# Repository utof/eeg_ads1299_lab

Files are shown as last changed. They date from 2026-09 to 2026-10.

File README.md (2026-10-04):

# ADS1299 Learning Lab

**Start without buying anything.** This is a runnable Python learning environment for EEG-like signals, an illustrative electrode/input circuit, signed 24-bit conversion, data transport, signal quality, and a small machine-learning experiment.

It is **not a finished EEG recorder, a validated PCB, or permission to attach a circuit to a person**. The firmware is a board-dependent **bench-only starter** using the ADS1299's internal test/short circuits. **Rev A selects an ADS1299-4 daughterboard plus ESP32-S3-DevKitC-1-N8R8 for simulation/schematic work; none of the hardware-review or body-connection gates are approved.**

## Open these first

| File | What it does for you |
|---|---|
| [START_HERE.html](START_HERE.html) | Offline visual walkthrough, provisional digital pin map, interactive gain/offset calculator. Open with the rest of the repository available. |
| [Agent instructions](AGENTS.md) / [GitHub publication runbook](docs/REPOSITORY_PUBLICATION.md) | Fresh assistant starts here; working publication methods, review boundaries and recovery checks. |
| [Development guide](docs/DEVELOPMENT.md) | Locked installation, one quality command, test-first changes, strict typing, and enforced public interfaces. |
| [DX validation record](docs/DX_VALIDATION.md) | A dated CI run with software tests, actual ngspice execution, native helper tests, and limitations. |
| [Historical results report](docs/RESULTS.md) | Original measured outputs and evidence; retained rather than overwritten by routine CI. |
| [Learning guide](docs/LEARNING_GUIDE.md) | A beginner explanation of the electronics, simulations, signal processing, and small exercises. |
| [Hardware guide](docs/HARDWARE_GUIDE.md) | Purchasing gate, $100 budget constraint, conditional wiring, bench tests, and the body-connection boundary. |
| [Rev A hardware baseline](docs/HARDWARE_BASELINE_REV_A.md) | Selected ADS1299-4 + ESP32-S3 components, machine-readable BOM/profile, fail-closed gates, and ordered next work. |
| [Experiments guide](docs/EXPERIMENTS.md) | From synthetic alpha to a future controlled meditation experiment, without confusing artifacts with consciousness. |
| [Next-session handoff](docs/LLM_HANDOFF.md) | Give this to a future assistant together with the source and validation records. |

The earlier uploaded reports are background, not software dependencies. This package does not depend on their old ZIP links or on an AD8232/ADS1115.

## First run: Linux, macOS, or Windows

Use Python **3.11 or newer**; Python 3.13 is the development default. CI exercises clean locked installations on Linux with Python 3.11 and 3.13. macOS and Windows are not currently covered by that CI matrix. `pyproject.toml` and `uv.lock` define the current dependencies; `requirements-tested.txt` is a historical validation record.

Clone or extract the repository, then open a terminal **inside `eeg_ads1299_lab`**:

```bash
uv sync --locked --all-extras
uv run --locked python run_lab.py demo
uv run --locked python -m tools.check
```

Install **uv 0.12.18** first using the [official installation instructions](https://docs.astral.sh/uv/getting-started/installation/). The standalone installer supports an explicit version in its URL. All project commands use `uv`; do not use a separately activated environment or bare Python/pip to run or modify this project. The editable installation makes imports work outside the checkout too.

The demo makes `reports/demo/synthetic_recording.npz`, event/quality CSVs, an analysis JSON, and four PNG figures. Live commands default to ignored `reports/`; committed `results/` examples are historical evidence. Use `--out reports/my_demo` for a separate run. The seed is fixed, but numerical outputs can vary slightly across dependency versions.

The quality command checks formatting, Ruff lint, strict Pyrefly typing, cognitive complexity, Tach import boundaries, the hardware baseline, software tests, and measured branch coverage. It includes the hardware-baseline tests that formerly needed a separate discovery command. Logs and reports go under `reports/check/`, not over historical evidence.

**A successful software check is not a native-simulator, firmware-target, or hardware pass.** Run the explicit native command below for native integration. `uv run --locked python run_lab.py verify` is now a compatibility entry point to the **same** `tools.check` gate. Add `--native` for native integration; `--require-ngspice` remains an alias. There is no competing historical-report verifier.

Before making changes, read [AGENTS.md](AGENTS.md) and install both the pre-commit and commit-message hooks:

```bash
uv run --locked pre-commit install
```

## Run a circuit simulation

```bash
uv run --locked python run_lab.py circuits --out reports/circuits
```

This solves the existing illustrative passive circuit using Python's linear algebra, writes response/tolerance CSVs, and exports two `.cir` files. The numerical solver is **not ngspice**. There is no transistor-level ADS1299 model, and the next Rev A-specific input-network model is separate work.

For a real ngspice cross-check and the full native gate on Debian/Ubuntu/Linux Mint:

```bash
sudo apt update
sudo apt install --no-install-recommends ngspice g++ nodejs
uv run --locked python run_lab.py circuits --require-ngspice --out reports/circuits
uv run --locked python -m tools.check --native
```

The strict commands fail when required tools are absent. The DX CI run recorded in [DX_VALIDATION.md](docs/DX_VALIDATION.md) actually executed ngspice and compared both educational circuits with the independent numerical solution. That newer CI evidence does not change what ran in the original historical validation environment. Simulator logs remain under the output folder.

## Three useful changes

```bash
# Negative control: remove the planted condition difference.
uv run --locked python run_lab.py demo --null-effect --out reports/my_null

# Eight physical channels and 60-Hz residual line interference.
uv run --locked python run_lab.py demo --channels 8 --line-hz 60 --out reports/eight_channels

# Edit a copy of this JSON to change gain, offset, or artifact size.
uv run --locked python run_lab.py demo --config configs/demo.json --out reports/custom
```

Changing a JSON changes the **simulation**, not a physical board. The firmware does not read `configs/demo.json` or the board-review worksheet.

## Test the recording path with no electronics

```bash
uv run --locked python -m tools.check --native
```

The native gate includes the real localhost UDP loopback: nine seconds of synthetic packets with samples 1000 and 2000 deliberately omitted, CSV decoding, and a gap-safe quality report. It checks 2,248 accepted packets and two missing samples. Unexpected extra loss causes a failure rather than a reassuring-looking plot. To run only the loopback, use `uv run --locked python -m tools.run_loopback --out reports/loopback`.

For manual control, use two terminals:

```bash
# Terminal A
uv run --locked python run_lab.py receive --seconds 15 --out reports/practice.bin
```

```bash
# Terminal B, while A is listening
uv run --locked python run_lab.py replay --seconds 8 --drop-every 1000
```

Then:

```bash
uv run --locked python run_lab.py decode reports/practice.bin --out reports/practice.csv
uv run --locked python run_lab.py inspect reports/practice.csv --out reports/practice_quality
```

Keep the `.json` metadata beside the decoded CSV. New captures include a SHA-256 binding the pair; inspection rejects a mismatched generation. Legacy captures without a digest remain readable with an explicit caution. The inspector analyzes only uninterrupted four-second windows. It reports DC offset separately and never fills gaps to manufacture a continuous spectrum. The receiver defaults to localhost; actual LAN use requires `--host 0.0.0.0`, private-network firewall permission, and the computer's LAN address in the firmware. UDP is unencrypted; never expose the port to the public internet.

## What is in the source?

```text
lab/adc.py              Ideal code scaling, range/headroom checks, sinc³ model
lab/analog/            Public analog facade; internal solver, SPICE, and report modules
lab/data_types.py      Typed numerical arrays and data/report contracts
lab/validation.py      Runtime validation at external-data boundaries
lab/signals.py          Deterministic, explicitly synthetic recordings
lab/dsp.py              Quality screens, band power, session-held-out classifier
lab/protocol.py         ADS frame decoding, custom packets, CRC and counters
lab/acquisition.py      UDP/optional bench serial logging and CSV decoding
lab/inspect_capture.py  Gap-safe bench spectra and quality reports
lab/recording.py        Synthetic recording validation and atomic NPZ persistence
lab/pipeline.py         Demo outputs and figures; compatibility persistence re-exports
hardware/rev_a/         Hardware-contract facade, checker, data, and tests
firmware/              Original-ESP32 bench starter; NOT target-compiled by the DX gate
configs/               Editable demo settings and hardware-review worksheet
results/               Historical example recordings, figures, logs, and reports
reports/               Ignored outputs from current quality/simulation runs
tests/                 Regression, property, architecture, and workflow tests
tools/check.py         Shared local/CI quality command
tools/commit_messages.py Conventional Commit hook and actual-history validation
tach.toml              Enforced public interfaces and dependency direction
```

The firmware's default `BOARD_PROFILE_REVIEWED = false` intentionally prevents acquisition startup. Changing that setting acknowledges **bench digital wiring only**, not body-use approval. Do not bypass it just to see a waveform.

## Rev A input-network study

The selected Rev A input components now feed a reproducible passive-network study, rather than remaining isolated hardware JSON. Start with the numerical calculation; then run the independent simulator comparison when ngspice is installed:

```bash
uv run --locked python -m lab.rev_a --out reports/rev_a_input
uv run --locked python -m lab.rev_a --require-ngspice --out reports/rev_a_input_native
```

The study validates and loads the locked 4.99 kOhm / 4.7 nF component values and BOM tolerances, checks an ideal-source reference, compares balanced and mismatched source impedances, evaluates eight tolerance corners per case, and reports 50/60 Hz common-mode conversion plus hypothetical DC leakage sensitivity. The native command actually runs six ngspice comparisons. `uv run --locked python -m tools.check --native` includes this study and retains its evidence under `reports/check/rev_a_input/`.

All source/load/parasitic assumptions appear in the report. Clamps remain DNP. **This is not an ADS1299 silicon, distributed-cable, BIAS-loop, physical-hardware or human-use safety model.** Read the [Rev A study guide](docs/REV_A_INPUT_STUDY.md) before interpreting the numbers.

## Contributing: uv and Conventional Commits

Use `uv sync --locked --all-extras` and `uv run --locked ...` for project work. Child processes launched with `sys.executable` inherit that locked interpreter; they do not create a second environment. CI bootstraps uv itself separately, then uses the same locked commands.

Commit subjects follow [Conventional Commits 1.0.0](https://www.conventionalcommits.org/en/v1.0.0/):

```text
feat(simulation): add a Rev A input-network sweep
fix(recording): reject discontinuous sample times
refactor(acquisition): stream decoded packets
chore(dx): synchronize issue labels
```

Use lowercase `feat`, `fix`, `docs`, `style`, `refactor`, `perf`, `test`, `build`, `ci`, `chore`, or `revert`; an optional lowercase scope describes the affected component. A breaking change uses `!` after the type/scope and should explain the incompatibility in a `BREAKING CHANGE:` footer. Subjects must have a nonempty description and no trailing whitespace.

The installed `commit-msg` hook checks the subject. CI checks **actual commits introduced by the PR**, not just its title. Old history is grandfathered. Actual merge commits are exempt, but writing “Merge” on a single-parent commit is not a bypass. **Merge PRs with merge commits: no squash and no history rewriting.** Validate a range locally with:

```bash
uv run --locked python -m tools.commit_messages --base origin/main --head HEAD
uv run --locked python -m tools.check --native
```

Issues use one `type/*`, one `priority/*`, and applicable `area/*` labels. Examples: `type/bug` + `priority/high` + `area/acquisition`, or `type/refactor` + `priority/medium` + `area/dx`. [The label manifest](.github/labels.json) owns names, colors, and descriptions; trusted-main housekeeping synchronizes it without deleting unrelated labels. Merged same-repository PR branches are removed only after ancestry and exact-head checks. Active or changed branches are retained.

Read [the adversarial review](docs/ADVERSARIAL_REVIEW.md) for the architecture verdict, reproduced failures, corrections, and remaining limits.

## Troubleshooting

| Symptom | First action |
|---|---|
| `ModuleNotFoundError` | Run `uv sync --locked --all-extras` and use `uv run --locked` with the repository environment. |
| Missing ngspice or native compiler | Install the required tool; do not count numerical Python tests as native execution. |
| Quality gate failed | Read the named log and `reports/check/CHECK_REPORT.json`; do not bypass the check. |
| `All epochs rejected` | Inspect gain, differential DC offset, and quality flags. An overrange input is an expected negative test. |
| No UDP packets | First repeat localhost loopback. Then inspect the private LAN address, firewall, and UDP port. |
| No four-second spectral windows | The capture is too short or fragmented. Fix acquisition before interpreting spectra. |
| Unexpected ESP32 or board pins | Stop; the supplied firmware pin map is not generic to every ESP32/ADS1299 module. |
| Matplotlib cache permission warning | Set `MPLCONFIGDIR` to a writable directory; no special font installation is required. |

Read [SOURCES.md](docs/SOURCES.md) for primary references and [MODEL_SCOPE.md](docs/MODEL_SCOPE.md) for model boundaries.

### Bounded BIAS overload hypothesis

`uv run --locked python -m lab.rev_a_bias_overload --require-ngspice` compares
a stated one-pole rail/slew hypothesis with ngspice while preserving feedback
capacitor charge. It is not measured ADS1299 overload recovery. Read
[the scope, source limits and numerical checks](docs/REV_A_BIAS_OVERLOAD.md).

### Shared-source analog-feed hypothesis

Run `uv run --locked python -m lab.rev_a_supply` for five independently checked
startup/burst cases of the selected analog-feed path. See
[the study and its assumptions](docs/REV_A_SUPPLY_STUDY.md). A completed numerical
comparison may expose a modeled rail-margin breach; neither outcome qualifies
the board or the separate TPS7A20 model.

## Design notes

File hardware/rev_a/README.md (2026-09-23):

# Rev A component baseline

Read [the hardware decision](../../docs/HARDWARE_BASELINE_REV_A.md) first.

**Selected:** ADS1299-4PAGR, ESP32-S3-DevKitC-1-N8R8, internal ADC reference/clock,
5 V unipolar bench power, and ADC-only TPS7A2033PDBVR regulation.

**Not authorized:** fabrication, purchasing, external-input operation or body connection.
The review flags are deliberately false. These JSON files are a design contract,
not a firmware implementation or a validated KiCad schematic.

```bash
python hardware/rev_a/check_baseline.py
python -m unittest discover -s hardware/rev_a -p 'test_*.py' -v
```

Run those commands from the repository root. Python 3.10+ and no third-party
packages are required. The checker also works when invoked by absolute path.

- `board_profile.json`: selected operating point, proposed GPIO/header assignments and review gates.
- `bom.json`: exact selected MPNs, reference counts, FIT/DNP population and planning costs.
- `sources.json`: primary sources, original-report SHA-256 hashes and access limitations.

This baseline was integrated after inspecting live `main` at
`31205de841c577c373532fbc9d065fa81d0a6ac8`. The existing firmware remains
unchanged and its board/target review guard stays fail-closed. The repository's
entry-point docs link here so future work does not reopen the component decision
by accident. Run the existing project tests and ngspice baseline on this branch
before changing the analog model or porting firmware to the S3.

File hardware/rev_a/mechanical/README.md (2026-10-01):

# K2 carrier CAD — unapproved fit prototype

Open **view_k2.scad** in OpenSCAD 2021.01. Select `assembly` or `exploded` in
Customizer, or an individual part. F6 renders solids. The library is
**carrier_k2.scad**; dimensions are millimeters in the PCB coordinate system,
with PCB top z=0. No fonts or external CAD library are needed.

See [the dimension/assembly/validation record](../../../docs/REV_A_CARRIER_K2.md)
before editing or interpreting meshes. The rendered board and connectors are
reference envelopes. The assembly is not one printable part. Export only a
named part after the separate prototype/process approvals; STL export alone
is not fabrication permission.

The base has no fasteners through the PCB. Remove the raised bridges for board
installation. J1/J2 bridge fastener spacings differ (30/36 mm). Socket cartridges
have different ribs/grooves, side cable windows and permanently captured cover
concepts. Remove/release the independent cable clamp BEFORE withdrawal. Real
socket orientation, printed dimensions, capture strength and mating behavior
are not verified by a picture or finite collision samples.

The native project gate now includes actual OpenSCAD collision/mesh checks:

```sh
uv run --locked python -m tools.check --native
```

It requires the documented native tools, including OpenSCAD 2021.01; no missing-
renderer skip is a pass. All purchasing, fabrication, powered-connection and
body-use gates remain unchanged. Current PCB source identity is recorded in
the linked document and checked by the tests.

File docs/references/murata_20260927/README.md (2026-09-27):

# Dated Murata evidence, not a second BOM

Read `../../REV_A_CAPACITOR_EVIDENCE.md`. `source_record.json` retains selected
factual fields from five exact-core rows in Murata's public catalog, the official
status legend, exact technical-PDF identities and capture receipts. The English,
Japanese and Chinese status columns are retained; `channel_code=jp` is not a
worldwide inventory claim. The current BOM remains the component source of truth.

Only core-to-current-D-suffix matches are established. No generic suffix-removal
or replacement-equivalence API is introduced. Body thickness maxima in the CSV
are separate from the nominal/tolerance values visually read from the PDFs.

This historical snapshot is tested offline for consistency, not polled in CI.
Retain it when later component decisions supersede it. Manufacturer technical
exports contain typical information, not approved assembly or a guaranteed
minimum effective capacitance. No PCN/date or replacement was established.

The complete catalog, internal coefficients and JavaScript are not redistributed.
The conversation package retains the five original technical PDFs, measurement
conditions, status images and capture hashes for review. CI success is not a
source-authenticity proof or permission to use hardware.

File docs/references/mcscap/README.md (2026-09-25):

# Owned MCScap electrodes: source facts, not a fitted circuit

Recorded 2026-09-24. The user reports owning MCScap electrodes with **insulated DIN 1.5 mm connectors**. The supplied family manual calls the connector **TouchProof** and describes passive, reusable Ag/AgCl cup electrodes. The exact catalogue variant, actual lead length and shielding are not yet known. Do not treat the selected ADS1299-4/S3 baseline as hardware already purchased.

## Preserved source

- [Complete user-supplied Russian manual transcription](MCS.MCE-UM-RU-RU_2024-10-31_user_transcription.txt): all supplied sections, including warnings, technical characteristics, use, maintenance and symbols. Presentation/line wrapping is normalized; technical wording, units and unusual values are not silently corrected.
- [Source record](source_record.json): manufacturer statements and user-reported inventory are separated from unknown numerical-model inputs. `null` means unknown, not zero.

The uploaded PDF was inspected, including the technical table. Its filename was `Электроды электроэнцефалографические MCScap. Руководство по эксплуатации .pdf`, 176,340 bytes, SHA-256 `23fd5e9f5d527dcd727f6707394ed6d6c9cc860d0810d6941f80eddcd2bb049a`. **The original PDF binary is not committed here.** This directory preserves the complete supplied text and identifies the exact attachment, not a claimed byte-identical PDF copy.

The [manufacturer document catalogue](https://docs.mks.ru/ru/product/eeg-electrodes) lists document `MCS.MCE-UM-RU-RU`, revision 1.0, 2024-10-31, 172 Kb. That catalogue entry was checked; the remote PDF was not binary-hash-compared with the upload.

## What the manual actually establishes

| Printed statement | Permitted interpretation | Not established |
|---|---|---|
| Electrode impedance no more than 5 kΩ | A manufacturer specification for the electrode under its applicable test conditions | A frequency-independent 5 kΩ resistor including the user's scalp contact; the test frequency/method is absent here |
| Electrode potential difference no more than 100 mV | A stated electrode-potential-difference limit | A measured offset of this connected recording system |
| Difference drift no more than 25 µV | A stated drift limit | µV/hour: the observation interval is unspecified |
| Electrode noise voltage no more than 20 µV | A stated noise-voltage limit | RMS or peak-to-peak amplitude, bandwidth, spectral density, or a white-noise parameter |
| Cable length no more than 2.5 m | Family upper bound | The actual cable length, shielding, capacitance per metre or capacitance location |
| Dielectric strength at least 30 V | A printed electrode insulation characteristic | Mains/patient isolation of the assembled EEG system |
| Insulation resistance at least 1000 Ω | Preserved exactly as printed in the supplied PDF | Permission to silently change the unit/value or use it as a patient-fault leakage model |

The manual itself says detailed characteristics depend on the manufacturer's catalogue number. The 1.5 mm diameter is **user-reported**, not separately specified in this family manual. A touch-protected/insulated connector is not a galvanic isolation barrier for the whole device.

## Modeling policy: this user's hardware first

Keep the existing Rev A three-scenario study as the clearly labelled numerical regression fixture it is. Do not relabel its 10 kΩ/100 nF assumptions as MCScap measurements or silently replace them with 5 kΩ.

The next electrode-specific study should use this source record, the actual catalogue variant and the available lead information. Represent missing frequency-dependent electrode/contact parameters explicitly. A 5 kΩ resistive example can be an **illustrative sensitivity case**, but not a manufacturer-calibrated model. Separate selected board components, published electrode facts, justified assumptions and physical measurements in every report.

Bad or asymmetric contact is still relevant to these same electrodes: the manual requires checking impedance and correcting contact when it increases. Keep a small set of normal/unequal/disconnected scenarios for the owned hardware; do not build an electrode-plugin system, generic registry or speculative device hierarchy. Introduce a reusable abstraction only when a second real use demonstrates duplication.

Before fitting parameters, obtain the exact catalogue suffix and actual lead length/shielding, and seek the impedance/noise test conditions or suitable dummy-bench measurements. Do not infer electrode capacitance from a single impedance upper bound.

No source statement here approves the Rev A circuit, its protection, its assembly, purchasing or connection to a person. The original hardware/firmware safety gates remain unchanged and false.

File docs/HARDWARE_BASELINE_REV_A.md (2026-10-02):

# Rev A hardware baseline: ADS1299-4 + ESP32-S3 bench daughterboard

**Decision date:** 2026-09-23  
**Base repository commit:** `31205de841c577c373532fbc9d065fa81d0a6ac8`  
**Status:** component and interface baseline for simulation/schematic work; **not** fabrication, purchasing, external-input, or human-connection approval.

## Decision

Use a four-channel `ADS1299-4PAGR` daughterboard connected to an official `ESP32-S3-DevKitC-1-N8R8`. Start at 250 SPS, gain 24, SPI mode 1 at 1 MHz, with the ADS1299 internal 4.5 V reference and internal clock. Use an externally regulated 5 V unipolar analog bench rail and a `TPS7A2033PDBVR` for **ADS DVDD only**; the ESP32-S3 remains on the devkit regulator.

Each differential channel starts with two 4.99 kΩ series resistors and one 4.7 nF C0G capacitor **across INP/INN**. No input-to-ground common-mode capacitors are fitted in Rev A. BIAS starts disabled; reserve 1 MΩ || 1.5 nF feedback plus a separate 1 MΩ output resistor for later dummy-load loop testing. Optional BAV199 steering-diode footprints are DNP initially.

This deliberately resolves the component ambiguity without pretending the hardware is validated. The existing original-ESP32 firmware guard and `BOARD_PROFILE_REVIEWED=false` behavior remain unchanged.

## Current component baseline

K1 amendment (2026-09-30): the two headers are now `HTSW-110-07-T-D`,
replacing the original TSW selection after its assembly restriction was identified.
Pin mapping, lands and routing are unchanged. See `REV_A_CONNECTOR_K1.md`;
exact attachment process, hole DFM and keyed carrier remain release conditions.
The original selection and price assumptions remain in Git history.

## Exact current parts

The machine-readable source of truth is [`hardware/rev_a/bom.json`](../hardware/rev_a/bom.json). Planning costs are allowances, not live supplier quotes.

| MPN | Qty | Population | Planning line cost |
|---|---:|---|---:|
| `ADS1299-4PAGR` | 1 | FIT | $45.00 |
| `ESP32-S3-DevKitC-1-N8R8` | 1 | FIT | $15.00 |
| `TPS7A2033PDBVR` | 1 | FIT | $1.20 |
| `RC0603FR-074K99L` | 8 | FIT | $0.64 |
| `GRM1885C1H472JA01D` | 4 | FIT | $1.60 |
| `RC0603FR-071ML` | 2 | FIT | $0.20 |
| `GRM1885C1H152JA01D` | 1 | FIT | $0.35 |
| `T491D107K016AT` | 1 | FIT | $2.00 |
| `T491B226K016AT` | 1 | FIT | $1.20 |
| `GRM188R61E105KA12D` | 15 | FIT | $2.25 |
| `GRM188R71H104KA93D` | 7 | FIT | $0.70 |
| `GRM219R61A106KE44D` | 4 | FIT | $1.40 |
| `RC0603FR-0710RL` | 1 | FIT | $0.08 |
| `RC0603FR-0710KL` | 5 | FIT | $0.30 |
| `RC0603FR-0742K2L` | 7 | FIT | $0.42 |
| `HTSW-110-07-T-D` | 2 | FIT | $4.00 |
| `B6B-XH-A(LF)(SN)` | 1 | FIT | $0.50 |
| `BAV199,215` | 8 | DNP | $2.40 |

Fitted components: **$76.84**. Bare-PCB reserve: **$15.00**. Harness/mating reserve: **$3.00**. **Planning subtotal: $94.84**. Optional BAV199 population adds $2.40. Shipping, tax/VAT/import charges, assembly/stencil/setup, tools, bench instrumentation, battery/charger, enclosure, and any patient-safety hardware are excluded. The $3.00 historical harness reserve is not evidence that the newly identified IDC assemblies and coded carrier fit that allowance. Obtain one delivered basket/assembly quote before purchasing; $94.84 is not a delivered total or a demonstration that the $100 objective is met.

C4 adds a dedicated six-way J3 service connector for the auxiliary circuit:
return, actual DVDD feed OUT, separate DVDD sense, AVDD sense, return, NC.
The 20-position headers are unchanged. See `REV_A_SERVICE_C4.md` for the
1:1 harness, native placement and open solder/crimp/physical-fit requirements.
The $0.50 addition is a planning allowance only; auxiliary electronics and the
new harness/support manufacture remain outside the old budget.

## Electrical contract

### Input network

```text
source P -- 4.99k --+---- ADS INxP
                     |
                   4.7 nF C0G
                     |
source N -- 4.99k --+---- ADS INxN
```

For an ideal zero-impedance differential source, the analytical pole is:

`1 / (2*pi*(4.99k + 4.99k)*4.7nF) = 3393.06 Hz`.

That is an RFI-network reference calculation, not an EEG passband specification and not a SPICE result. Electrode/source impedance and mismatch must be swept explicitly.

### Power

```text
regulated 5.0 V bench source
  +-- 10 ohm RC feed --> quiet analog rail --> ADS AVDD / AVDD1
  +-- TPS7A2033PDBVR --> 3.3 V --> ADS DVDD only
  +-- devkit 5 V input --> onboard regulator --> ESP32-S3
```

Do not power the ESP32-S3 from the ADS DVDD regulator. Do not simultaneously power the devkit from USB and its external 5 V header. The analog feed resistor is a filter element, not a regulator; the design envelope in `board_profile.json` must remain within the ADS operating rail range.

### Reference / VCAP baseline

Use the ADS1299 internal reference and clock. The selected baseline includes 100 µF solid tantalum at VCAP1, 22 µF solid tantalum across VREFP/VREFN, local 1 µF supply/VCAP capacitors, 100 nF high-frequency bypass, and 10 µF local rail bulk capacitors. Final schematic review must verify every pin, polarity, effective capacitance under bias, and datasheet-required connection.

### Proposed S3 signal map

| Signal | ESP32-S3 GPIO | ADS1299 pin |
|---|---:|---:|
| SCLK | 12 | 40 |
| MOSI/DIN | 11 | 34 |
| MISO/DOUT | 13 | 43 |
| CS | 10 | 39 |
| DRDY | 4 | 47 |
| RESET | 5 | 36 |
| START | 6 | 38 |
| PWDN | 7 | 35 |
| CLKSEL | 8 | 52 |

This map is **proposed, not bench-verified**. GPIO8 is exposed on the official
DevKitC-1 v1.1 header and is reserved here for CLKSEL so the ADS input can stay
low during rail startup and be asserted only after supplies stabilize. J_DIG pin
19 carries CLKSEL; the former passive DVDD sense assignment is removed.

The ADS1299 power-up sequence requires its digital and analog inputs low until
the supplies stabilize. Therefore SCLK, DIN/MOSI, CS, RESET, START, PWDN and
CLKSEL all have a declared power-up level of 0 in `board_profile.json`. CS and
CLKSEL use 42.2 kΩ pulldowns after the coordinated C3 light-load migration, not pullups.
All seven receiver-side bus defaults use the same 42.2 kΩ value; the reserved
CLK/GPIO1-4 terminations stay 10 kΩ. See `REV_A_AUXILIARY_C3.md` for the
conditional loaded-high/disabled-low budget; no power-up/fault qualification follows. The intended operational CLKSEL level
remains 1 for the internal oscillator; firmware must make that transition only
after the supply-stable boundary. This contract does not claim that rail timing
has been measured. CLK itself (ADS pin 37, not pin 51) has a fitted 10 kΩ
`R_CLK_DN` to DGND: CLKSEL low selects that external-clock input during startup.
This adds one instance of the already selected resistor, a $0.06 planning allowance,
not a new part family. Clock output remains disabled.

The firmware does not load `hardware/rev_a/board_profile.json`; the explicit
`EEGLAB_REV_A_S3` header is checked against it in tests. Its reviewed path now
executes the controlled startup sequence in
[`REV_A_STARTUP_SEQUENCE.md`](REV_A_STARTUP_SEQUENCE.md). The review gate stays
false; a successful build does not authorize changing it.

**Analog startup remains a physical precondition, not a digital-GPIO result.**
The passive R/C input network does not hold a floating external input low. Before
any reviewed power-up, a separately reviewed passive startup fixture must hold
the used analog inputs low; no person or powered source may be attached. The
serial rail/fixture confirmation is only an operator acknowledgment. It neither
measures those inputs nor supplies an automatic back-powering interlock. Do not
claim that this contract alone satisfies the complete datasheet startup rule.

## Fail-closed gates

Rev A keeps all of these false:

```json
{
  "board_profile_reviewed": false,
  "firmware_port_validated": false,
  "schematic_released": false,
  "purchase_approved": false,
  "human_connection_allowed": false
}
```

No person or animal should be connected to this Rev A design. Battery operation, Wi-Fi, a USB isolator, low-leakage clamps, or a high-value BIAS resistor do not by themselves establish system safety.

## Validation

From the repository root:

```bash
uv run --locked python hardware/rev_a/check_baseline.py
uv run --locked python -m unittest discover -s hardware/rev_a -p 'test_*.py' -v
```

These checks verify the declarative BOM/profile contract, quantities, pin conflicts, cost arithmetic, frame length, provenance references, and fail-closed gates. They do **not** run SPICE, compile firmware, perform KiCad ERC/DRC, measure hardware, or certify safety.

## Next work, in order

1. **Implement the Rev A input network in ngspice.**
   a. Preserve the existing educational circuit as a regression fixture.  
   b. Add the selected 4.99 kΩ / 4.7 nF differential network and explicit source/electrode impedance.  
   c. Sweep impedance imbalance, R/C tolerance, cable capacitance, 50/60 Hz common mode, and bounded clamp leakage.  
   d. Compare the ideal case to 3393.06 Hz and commit numerical regression tests.

2. **Model BIAS and power behavior.**
   a. Add a bounded behavioral BIAS amplifier, the 1 MΩ / 1.5 nF network, dummy electrode/cable loads, and saturation.  
   b. Sweep uncertain loop parameters and check stability/recovery.  
   c. Model analog-rail startup and burst-like MCU/radio current coupling.

3. **Create the KiCad schematic and explicit ESP32-S3 firmware profile.**
   a. Use the exact BOM and four-channel pin rules.  
   b. Preserve all firmware guards and keep external-input acquisition disabled.  
   c. Compile supported targets and test ID/register readback plus 4/6/8-channel frame handling.

4. **Layout, quote, and bench bring-up.**
   a. Four-layer layout, ERC/DRC, reference/VCAP locality, controlled return paths, radio separation.  
   b. Obtain a delivered parts/fabrication/assembly quote before ordering.  
   c. Bring up rails -> ID/registers -> internal test -> input-short noise -> reviewed dummy source -> radio on/off comparison.

5. **Treat any body-connected design as a later revision.**
   a. Resolve battery/charging separation, enclosure, electrode connector/protection, BIAS fault paths, and qualified safety review.  
   b. Revalidate analog/noise behavior after those changes; bench success is not patient-safety evidence.

## Provenance

Detailed primary-source URLs, the two research-report hashes, verification notes, and the inspected upstream SHA are in [`hardware/rev_a/sources.json`](../hardware/rev_a/sources.json). Dynamic stock/pricing should be rechecked at purchasing time.

## Native schematic correction

The schematic slice removes `R_DAISY_DN`: unused DAISY_IN (pad 41) connects
directly to DGND, following TI SBAS499C section 10.1.1. The separate CLK pad 37
pulldown remains fitted. This retires one instance, not a part family, and reduces
the preceding planning total by $0.06. These are allowances, not supplier quotes.

The native schematic and its independent exported-netlist checker are described
in `REV_A_SCHEMATIC.md`. All physical review, purchasing and body-use gates stay false.

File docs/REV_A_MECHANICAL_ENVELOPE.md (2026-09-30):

# Rev A mechanical and assembly envelope M1

**Reviewed source:** `8c3440ed6714bfebaac74768a0d371401a22e89e`, tree
`81acc1aa34c29faa7a0305d2247826909a6c2f13`. Authored board SHA256
`5da65b4307f0336883da9aeae48711b28c1944ec587f5d3174f12db4e9921875`.
M1 is a selected mechanical planning envelope, not a released fixture or
manufacturing approval. No copper, holes, footprints, BOM or firmware change.

## Decision and concrete assembly blocker

**Retain the existing outline and use an external nonconductive edge carrier,
with independently supported controller and cable strain relief.** Four small
contact regions below pass a source-geometry screen. No new mounting hole is
required for this concept. Do not drill, clamp arbitrary edges, place metal
washers under the board, or use the headers as structural supports. Carrier
material, retention force, board deflection, contamination, dimensional
variation and physical fit still need a drawing and validation. The selection
is a way forward without rerouting, not proof that any generic holder fits.

**The present TSW-110-07-T-D headers must not be included in an assumed
lead-free SMT reflow process.** Samtec's TSW/HTSW catalog identifies TSW as
PBT and lists it as not lead-free solderable, with lead-wave-only processing;
it separately lists HTSW as lead-free solderable [1]. The combined SSW/TSW/SMH
specification's reflow section explicitly discusses *surface-mount* parts and
labels its temperature tables SMT [5]. Its generic reflow-pass paragraph is not
an exact-orderable exception to the through-hole TSW catalog restriction.
Tin plating or RoHS status alone is not process compatibility.

Select a staged assembly architecture: SMT components first, headers excluded
from that operation. **The subsequent header attachment process is on hold**
until the exact TSW process is accepted in writing or a high-temperature header
alternative is reviewed and migrated consistently. This is not permission to
hand-solder TSW with an unverified lead-free profile, use a leaded process, or
silently replace it with HTSW. All other stencil/land/reflow decisions stay open.

**Next bounded task:** evaluate the same-function high-temperature header route
and a polarized actual mate/strain-relief arrangement. Resolve the connector
process choice before a coordinated BOM/schematic/PCB-field/test change and
final carrier drawing. This is one connector/process decision, not a new layout
or an open-ended catalog search. Keep capacitor #48 and remaining #45 inputs open.

## What the authored board actually provides

The single Edge.Cuts rectangle runs from **(10,10) to (88,68) mm**: nominal
**78 x 58 mm**. KiCad's 78.05 x 58.05-mm graphic bounding box includes the
0.05-mm outline stroke; it is not the board's specified physical size. Finished
outline and thickness tolerances need the factory drawing. Nominal thickness
is 1.6 mm, with the previously selected but unconfirmed stackup target.

All 68 footprints are front-side; eight diode bodies are DNP. There are 205 SMD
pads and 40 plated through-hole header pads, **no NPTH mounting pads and no
separate mounting-hole footprint or internal Edge.Cuts cutout**. The 122 signal/
power vias are not mounting holes. The ground plane and buried copper remain
under some mechanically empty surface regions.

Coordinates below are top-view native board coordinates, not a mating-face
view. Both header footprint rotations are zero. Each row advances +2.54 mm
in y; odd pins are the lower-x column and even pins the higher-x column.

| Header | Function | Pad 1 (x,y) mm | Pin-grid centre mm | Pin-grid x / y range mm |
|---|---|---|---|---|
| AFE J1 | Digital/power | (80,27) | (81.27,38.43) | 80..82.54 / 27..49.86 |
| AFE J2 | Dummy analog input | (15,32) | (16.27,43.43) | 15..17.54 / 32..54.86 |

The same unkeyed 2x10 form serves electrically incompatible functions. Reversed,
one-position-offset and wrong-header mating must be prevented by the final
mechanical arrangement and verified unpowered before any later allowed test.
Labels alone are not a mechanical interlock. Do not remove an arbitrary pin:
J1's full map is assigned and J2's unused positions are still part of the
current contract. Preserve AFE/DEVKIT prefixes and the existing wiring map.
`REV_A_BENCH_HARNESS.md` now describes the actual layout rather than saying no
layout exists. No cable, keyed connector or live interface was qualified here.

## Mating allocation, not an arbitrary plug guarantee

M1 reserves **8 mm across the rows by 28 mm along them**, centred on each pin
field. These are chosen planning dimensions, not measured or manufacturer
maximum plug dimensions. They exclude fingers/tools, cable bend radius,
connector sway, tails, adapter boards and strain relief, which need their own
external volumes. No closed enclosure is selected.

| Allocation | (xmin,ymin,xmax,ymax), mm | Nearest other courtyard AABB gap | Board-edge margin |
|---|---|---:|---:|
| J1 | (77.27,24.43,85.27,52.43) | C33: 0.726 mm | 2.730 mm |
| J2 | (12.27,29.43,20.27,57.43) | D1/D3/D5/D7: 1.300 mm | 2.270 mm |

Courtyard-centreline bounding boxes conservatively screen the footprint
neighborhood, including DNP diode courtyards. They are not guaranteed assembly
or tool-clearance envelopes. The tightest neighbor is the C33 corner; changing
the plug, candidate body or placement tolerance requires rechecking it.

**Geometry reference only:** Samtec SSW-110-01-T-D is a same-pitch socket with
about 25.91-mm body length, 4.95-mm reference width and 8.51-mm height [3,4].
It has PCB tails, not a finished cable/strain-relief assembly, and is not being
added to the BOM. The drawing's +/-0.25-mm length tolerance, cut flash and sway
must be included in an actual assembly fit review; the width is marked REF.
This is a nominal fit screen, not a worst-case mate certification.

TSW style07 has a 5.84-mm nominal mating post and 2.54-mm reference body
height: nominal unmated height **8.38 mm**. The SSW insertion-depth interval is
3.68..6.35 mm [1,3]. The nominal post lies in that interval, but actual seating
and tolerances remain to be checked. Adding 2.54 and 8.51 gives **11.05 mm**
as a nominal fully seated shell-top estimate, not a guaranteed board-to-board
spacing. Carrier clamps must not obstruct withdrawal or cause board bending.

## Heights and board support

| Item | Reference maximum L x W x H, mm | Centred body-to-own-courtyard AABB margin |
|---|---|---:|
| Proposed 10-uF bulk, C30-C33 | 2.10 x 1.35 x 1.35 | 0.305 mm |
| Proposed 1-uF/100-nF, C8-C29 | 1.70 x 0.90 x 0.90 | 0.280 mm |
| Existing T491D C6 | 7.60 x 4.60 x 3.10 | 0.250 mm |
| Existing T491B C7 | 3.70 x 3.00 x 2.10 | 0.250 mm |

The candidate bulk is 0.40 mm taller than the old part but does not exceed
C6's reference height. Murata bounds come from the previously retained exact
reference records, not an 0805-name assumption; the candidates remain unadopted.
KEMET's current captured dimensions match the existing July2026 land source
[7]. Centred-body containment excludes placement error, solder, termination
fit and process tolerances, so it does not approve the land or component change.
U1's PAG drawing separately specifies 1.20-mm maximum overall height [6].

Choose **4 mm free height over the SMT field**, **15 mm open vertical space over
each header mating allocation**, at least **6 mm further unobstructed withdrawal
travel above the actual mated shell**, and **5 mm board-underside-to-base space**
as carrier design starting points. No lid/tool/fixture is qualified by those
numbers. Cable and adapter protrusions can exceed them and must be accommodated.
For scale, the nominal 2.54-mm TSW tail minus a nominal 1.6-mm board is 0.94 mm;
using the earlier overall minimum thickness1.44 gives1.10 mm before terminal
variation and solder. Neither calculation bounds the actual finished protrusion.
Inspect actual solder/tails, board warp and fixture tolerances before assembly
acceptance. Do not rely on soldermask as the fixture's insulation system.

Four selected **1.5 x 6 mm surface-contact strips** are below; dimensions are
planning allocations, not a supplied or fabricated clamp. Support and removable
retention stay within them; the base fastens outside the PCB. Add strain relief
on the carrier, not on sensitive leads or component bodies. This is not a tested
load/deflection model or permission for a suspended mating daughterboard.

| Region | (xmin,ymin,xmax,ymax), mm | Outer pad/track/via AABB gap | Courtyard gap | Mate-allocation gap |
|---|---|---:|---:|---:|
| Left upper | (10,32,11.5,38) | 1.300 | 1.730 | 0.770 |
| Left lower | (10,48,11.5,54) | 1.300 | 1.730 | 0.770 |
| Right upper | (86.5,27,88,33) | 3.110 | 2.180 | 1.230 |
| Right lower | (86.5,43,88,49) | 3.110 | 2.180 | 1.230 |

These distances are conservative AABB lower bounds on current outside copper,
not actual minimum trace-to-contact distances in three dimensions. The screen
explicitly rejects unsupported outer pours/copper graphics; there are none in
this source. It includes through vias and both outer pad/track layers. Buried
copper, mask damage, edge registration, friction, material leakage, cleanliness
and insertion forces are NOT qualified. Surface clearance is **not permission
to drill into these locations** or automatically reserve a copper keepout.

Samtec recommends independent support for board-to-board mating [5]. M1 applies
that principle through an external carrier because the present PCB has no
mount holes. Actual insertion/extraction force and permissible board strain
must be determined with the chosen mate and carrier, not guessed from pin count.

The existing 1.00-mm header drills also differ from the manufacturer's 1.02-mm
nominal callout [2]. A nominal0.635-mm square post has a0.898-mm diagonal, but
that arithmetic does not include terminal, hole/plating or positioning tolerances.
Keep hole/annulus and process review open; no automatic drill or pad resize.

## Reproduce the source screen

Run this read-only block from the repository root using the system Python
which supplies the pinned KiCad9.0.2 `pcbnew` module. It does not refill/save the
board or create a production dependency. It derives the counts, header grids,
rectangles, gaps and centred-capacitor projections, then checks the retained
record. The record's parameters are chosen allowances; the code does not
revalidate vendor drawings, mechanical force or a real fixture. AABB distance
is deliberately conservative, not a generic exact collision solver.

```python
import hashlib
import json
import math
from pathlib import Path
import pcbnew as k

record = json.loads(Path("docs/checkpoints/20260930_mechanical_envelope.json").read_text())
path = Path("hardware/rev_a/layout/rev_a.kicad_pcb")
assert hashlib.sha256(path.read_bytes()).hexdigest() == record["board_sha256"]
assert k.Version() == "9.0.2"
b = k.LoadBoard(str(path))

def point(p):
    return [p.x / 1e6, p.y / 1e6]

def box(p):
    return [p.GetX() / 1e6, p.GetY() / 1e6, p.GetRight() / 1e6, p.GetBottom() / 1e6]

def span(points):
    return [
        min(p[0] for p in points),
        min(p[1] for p in points),
        max(p[0] for p in points),
        max(p[1] for p in points),
    ]

def separation(a, z):
    return math.hypot(max(a[0] - z[2], z[0] - a[2], 0), max(a[1] - z[3], z[1] - a[3], 0))

def margin(inner, outer):
    return min(inner[0] - outer[0], inner[1] - outer[1], outer[2] - inner[2], outer[3] - inner[3])

fps = {f.GetReference(): f for f in b.GetFootprints()}
pads = [p for f in fps.values() for p in f.Pads()]
tracks = list(b.GetTracks())
edges = [g for g in b.GetDrawings() if g.GetLayer() == k.Edge_Cuts]
assert len(edges) == 1 and edges[0].GetShape() == k.SHAPE_T_RECT
outline = span([point(edges[0].GetStart()), point(edges[0].GetEnd())])
counts = [
    len(fps),
    len(pads),
    len(tracks),
    sum(p.GetAttribute() == k.PAD_ATTRIB_NPTH for p in pads),
    sum(p.GetAttribute() == k.PAD_ATTRIB_PTH for p in pads),
    sum(f.GetLayer() == k.F_Cu for f in fps.values()),
]
assert counts == record["counts_footprints_pads_copper_NPTH_PTH_front"]
assert outline == record["outline_centerline_bbox_mm"]
courts = {}
for ref, f in fps.items():
    gs = [g for g in f.GraphicalItems() if isinstance(g, k.PCB_SHAPE) and g.GetLayer() == k.F_CrtYd]
    assert gs and all(g.GetShape() in (k.SHAPE_T_SEGMENT, k.SHAPE_T_RECT) for g in gs)
    courts[ref] = span([point(p) for g in gs for p in (g.GetStart(), g.GetEnd())])
# This board has no outer-layer zones or copper graphics; don't silently ignore new ones.
assert all(z.GetLayer() == k.In1_Cu for z in b.Zones())
assert not any(g.GetLayer() in (k.F_Cu, k.B_Cu) for g in b.GetDrawings())
assert not any(g.GetLayer() in (k.F_Cu, k.B_Cu) for f in fps.values() for g in f.GraphicalItems())
outer = [
    box(x.GetBoundingBox()) for x in pads + tracks if x.IsOnLayer(k.F_Cu) or x.IsOnLayer(k.B_Cu)
]
allocations, header_rows = {}, []
for ref in ("J1", "J2"):
    f = fps[ref]
    ps = {p.GetNumber(): p for p in f.Pads()}
    origin = point(ps["1"].GetPosition())
    assert len(ps) == 20 and f.GetOrientationDegrees() == 0
    for n in range(1, 21):
        expected = [origin[0] + ((n - 1) % 2) * 2.54, origin[1] + ((n - 1) // 2) * 2.54]
        assert all(abs(a - z) < 1e-6 for a, z in zip(point(ps[str(n)].GetPosition()), expected))
        assert point(ps[str(n)].GetDrillSize()) == [1.0, 1.0]
    grid = span([point(p.GetPosition()) for p in ps.values()])
    cx, cy = (grid[0] + grid[2]) / 2, (grid[1] + grid[3]) / 2
    width, length = record["mate_allocation_width_length_mm"]
    a = [cx - width / 2, cy - length / 2, cx + width / 2, cy + length / 2]
    near, neighbor = min((separation(a, c), r) for r, c in courts.items() if r != ref)
    assert margin(a, outline) >= 2 and near >= 0.5
    allocations[ref] = a
    header_rows.append([ref, origin, a, margin(a, outline), neighbor, near])
support_rows = []
for label, a in record["support_contact_rectangles_mm"].items():
    assert margin(a, outline) >= 0 and a[0] < a[2] and a[1] < a[3]
    distances = [
        min(separation(a, c) for c in outer),
        min(separation(a, c) for c in courts.values()),
        min(separation(a, c) for c in allocations.values()),
    ]
    # Selected screening allowances, not manufacturer tolerances or force qualification.
    assert distances[0] >= 1 and distances[1] >= 0.5 and distances[2] >= 0.5
    support_rows.append([label, *distances])
body_rows = []
for group in record["body_reference_groups"]:
    lx, ly, h = group["maximum_L_W_H_mm"]
    margins = []
    for ref in group["references"]:
        f = fps[ref]
        cx, cy = point(f.GetPosition())
        angle = -math.radians(f.GetOrientationDegrees())
        pts = [
            [
                cx + x * math.cos(angle) - y * math.sin(angle),
                cy + x * math.sin(angle) + y * math.cos(angle),
            ]
            for x in (-lx / 2, lx / 2)
            for y in (-ly / 2, ly / 2)
        ]
        margins.append(margin(span(pts), courts[ref]))
    assert min(margins) > 0
    body_rows.append([group["name"], h, min(margins)])
result = {"headers": header_rows, "supports": support_rows, "body_groups": body_rows}

def compare(actual, saved):
    if isinstance(actual, (int, float)):
        assert isinstance(saved, (int, float)) and math.isclose(actual, saved, abs_tol=1e-6)
    elif isinstance(actual, list):
        assert isinstance(saved, list) and len(actual) == len(saved)
        for a, z in zip(actual, saved):
            compare(a, z)
    else:
        assert actual == saved

for key, value in result.items():
    compare(value, record["observed"][key])
print(json.dumps(result, indent=2))
```

## Evidence and remaining exit conditions

Source-capture36754120103 checked out exactmain8c3440 from GitHub and preserved
its original history. Primary capture36755627629 retained eight PDFs and their
hashes; the checkpoint lists exact URLs/byte identities/revisions. Relevant
pages were inspected as rendered images, not inferred from an unrelated part.
The generic spec's web screenshot failed; its independently downloaded native
PDF page was rendered and inspected instead. Full PDFs are not required project
dependencies and are not incorporated into this product source.

Native/source comparison independently checked all704 track/via forms and245
pad positions, all68 footprint origins and the actual outline. The exact
reproduction above passed. Three changed-record probes were executed and rejected: a support moved into
copper, a mating allocation widened into a neighbor, and an altered retained
clearance result. Original data was restored and the exact block passed again.
These are documentary/data controls, not physical or new project tests. Final PR execution/review must be
read at its actual head; previous CI successes do not validate this source.

M1 closes the initial envelope selection, not the assembly/fixture release.
Next resolve the TSW process/high-temperature alternative plus a physically
polarized mate and cable support, then finalize carrier dimensions/tolerances.
Keep #45/#48, capacitor qualification, factory stack, real powered-off console
behavior, measurement fixture/floor and delivered budget open. No procurement,
fabrication, powered connection, body use or approved insulation is claimed.

## Primary references, checked 2026-09-30

[1] Samtec TSW/HTSW through-hole catalog F-226, pp1-2:
https://suddendocs.samtec.com/catalog_english/tsw_th.pdf
[2] Samtec TSW market drawing revDS, sheets2,6 and footprint revA:
https://suddendocs.samtec.com/prints/tsw-xxx-xx-xxx-x-xx-xxx-mkt.pdf
https://suddendocs.samtec.com/prints/tsw-xxx-xx-x-x-xx-xxx-footprint.pdf
[3] Samtec SSW/SSQ through-hole catalog F-226:
https://suddendocs.samtec.com/catalog_english/ssw_th.pdf
[4] Samtec SSW drawing revCL, sheet1:
https://suddendocs.samtec.com/prints/ssw-1xx-xx-xxx-x-xx-xxx-xx-mkt.pdf
[5] Samtec combined SSW/TSW and SMH/TSW product specification revC,
2023-02-08, pp5-6 (SMT processing versus independent supports):
https://suddendocs.samtec.com/productspecs/tsw-sxx.pdf
[6] TI ADS1299 SBAS499C, PDFp81, PAG drawing4040282/C:
https://www.ti.com/lit/ds/symlink/ads1299.pdf
[7] KEMET T2005_T491, captured2026-07-08 edition, p4:
https://content.kemet.com/datasheets/KEM_T2005_T491.pdf
Murata candidate dimensions: existing `bulk_orderable_addendum.json` and
`20260930_capacitor_e1.json`, retaining their exact suffixes and dated-reference
limits. Do not rewrite those historical records as new approval specifications.

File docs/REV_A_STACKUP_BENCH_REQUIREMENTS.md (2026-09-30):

# Rev A stackup target and person-disconnected bench requirements

Decision record E1, 30 September 2026. Base source `8403c4eefc6fd6f1303a75510755f16f983e71c4`,
tree `4f5bebbc578c15f63c3463f2b3cef0bd28fbdfa9`; authored PCB SHA256
`5da65b4307f0336883da9aeae48711b28c1944ec587f5d3174f12db4e9921875`.

**Select JLCPCB JLC04161H-7628 as the design-stack target, and E1 below as the
first dummy-source performance target.** These are explicit engineering choices
made here, not measurements, previously supplied user requirements, an order,
or a claim that ordinary electrodes meet this envelope. The vendor's detailed
build tolerances and the actual bench fixture remain unconfirmed. No source
CAD, BOM, firmware, model, dependency or approval flag changes in this slice.

## 1. Named construction, without inventing factory tolerances

Use the named **1.6-mm, four-layer, 1-oz outer / 0.5-oz inner** construction [1].
Retain the authored F / In1 GND / In2 routed copper / B assignment. Do not rename
In2 a plane or imply that In1 shields the remaining B/In2 crossings.

| Layer or dielectric | Selected table value | Reference/design role |
|---|---:|---|
| F.Cu | 0.035 mm | Components and principal analog/digital paths |
| 7628 prepreg | 0.21040 mm, nominal effective Dk 4.4 | F to In1 |
| In1.Cu | 0.0152 mm | Existing connected GND fill |
| Core | 1.065 mm; stackup page Dk 4.6 | In1 to In2 |
| In2.Cu | 0.0152 mm | Existing routed supplies/signals, NOT a plane |
| 7628 prepreg | 0.21040 mm, nominal effective Dk 4.4 | In2 to B |
| B.Cu | 0.035 mm | Existing back copper |

The tabulated sum is **1.5862 mm before soldermask**, not a new nominal order
thickness. JLC's guide says finished thickness includes mask, prepreg values
are pressed thicknesses, and dielectric constants are process-derived [2,3].

The compared JLC04161H-3313 table uses 0.09940-mm outer gaps and a 1.265-mm core
[1]. It places F nearer GND but also places B nearer routed In2. Choosing 7628
is a compromise for the existing layout, not a proof of lower total coupling,
a cheapest delivered quote or an impedance guarantee. Do not estimate actual
mutual capacitance by treating the six trace-union areas as isolated plates.

**Material target: Nan Ya NP-155F**, the named 4-8-layer calculator material [2],
subject to written availability/build confirmation; do not accept an unspecified
FR-4 substitution on the strength of a stackup ID. The public sources need
reconciliation: the stackup page lists **35 um** outer copper / core Dk **4.6**;
the calculator guide uses **1.6 mil = 40.64 um** / **4.43 for cores >0.70 mm**
[1,2]. Those are distinct published reference values, not statistical limits.

JLC publishes **1.6 mm +/-10% overall thickness** and **+/-20% track width**
[4]. Neither is a guarantee of +/-10% on EACH dielectric gap, Dk, copper
thickness, registration or coupling. No such per-layer guarantee was found.
The existing 0.15-mm traces and 0.60/0.30-mm vias are not a substitute for DFM:
their nominal 0.15-mm annulus sits at the published multilayer PTH absolute
minimum, below its 0.20-mm recommendation [4]. Via-specific acceptance, drill
compensation and pad holes must be checked by the vendor; no automatic via resize.

### Factory confirmation needed before releasing build data

Request a dated job-specific drawing with the exact stack ID, laminate grade,
finished/pressed dielectric min/nominal/max, copper min/nominal/max, applicable
Dk/frequency/material ranges, layer registration and through-hole process.
Ask the vendor to resolve the two public-value differences above and to review
the existing fine-pitch copper, 0.60/0.30-mm vias and connector holes. Require
no substitutions without a new review. This is a prepared request, **not a sent
message or obtained confirmation**. The order price, finish, assembly and
material availability are not established by this record.

For a provisional sensitivity sweep only, examine outer gaps 0.17-0.25 mm and
Dk 4.0-4.8, as well as both published copper/core-Dk values. These are deliberately
chosen analysis intervals, **not vendor-supported bounds** and not sufficient
for worst-case sign-off. If the confirmed stack lies outside them, recompute.
Do not encode an unconfirmed stack into fabrication outputs or call it released.

## 2. E1 numerical target: a limited dummy-bench configuration

The purpose is to resolve a **10-uV-peak, 10-Hz reference stimulus** with useful
margin while retaining the current 250-SPS, gain-24 architecture. It is not a
clinical EEG specification. Existing internal-test/input-short modes remain
the only initially enabled modes; external dummy acquisition stays disabled.
Fixture/startup/interface review is required before any later powered test.

| Quantity | E1 requirement/definition |
|---|---|
| Environment | Person/animal disconnected; 20-30 degC; one reviewed bench-power arrangement; Wi-Fi/BLE, BIAS, lead-off and SRB routing off |
| Acquisition | Existing 4-channel, 250-SPS nominal, gain 24, internal 4.5-V reference, 2.048-MHz nominal clock; SPI mode 1, 1 MHz; no firmware changes here |
| Performance band | 1-40 Hz. Diagnose 50/60 Hz separately on the unnotched record. Do not claim a flat 65-Hz passband |
| Qualified-target source family | Calibrated resistive dummy sources 1-10 kohm per leg, P/N matching within 0.1%; verify endpoints 1k/1k and 10k/10k. This is NOT a scalp-impedance range |
| Fixture loading | At J2, no more than 100 pF to local return per leg, mismatch no more than 1 pF; measure including leads/adapters. Not a bound on ADS/PCB parasitics |
| Actual AFE load | Unchanged ADS1299 plus fitted R/C and DNP copper. TI gives 1-Gohm minimum DC input impedance without lead-off and 20-pF typical input capacitance [5]; 20 pF is NOT a maximum or a validated per-leg shunt model |
| Differential input | 10 uV to 10 mV peak AC; DC offset up to +/-50 mV; sum never exceeds 60 mV peak magnitude at the PGA. No overload/stimulation/body claim |
| Common mode | 2.5 V nominal; entire instantaneous excursion 2.40-2.60 V, including injected common mode; no source connected during unreviewed/unpowered startup |
| Rails | Existing AVDD operating range 4.75-5.25 V includes all ripple; DVDD nominal 3.3 V. Source remains the selected regulated 5-V topology, not DevKit USB power |
| Signal transfer | After one 10-Hz gain calibration, amplitude response at 1, 5, 10, 20 and 40 Hz must be within 5% of the declared passive network times sinc3 response NORMALIZED at 10 Hz; retain uncorrected data and calibration uncertainty |
| Total noise | At most **0.50 uV RMS**, integrated 1-40 Hz, each channel, all E1 sources quiet and terminated, normal SPI/UART activity; no notching or removal of in-band lines to pass |
| Internal-short diagnostic | At most **0.30 uV RMS** in the same band; additional troubleshooting criterion, NOT a replacement for the externally terminated test |
| Coherent error | At most **0.50 uV peak per victim/frequency**, with the component allocations below, including uncertainty. Broadband RMS noise is a separate condition |
| Record | At least 64 s AFTER 2 s of settling; measure actual sample rate, do not assume exactly 16000 samples or ideal clock frequency; no missing/clipped frames |

All error/noise voltages are ADC-input-equivalent values from calibrated code
scale (nominally Vref/(gain*2^23) per code, TI Equation 8), **without inverse-filter equalization**.
Coupling H includes the actual acquisition filtering; its denominator is the
measured aggressor node amplitude. Transfer-shape calibration above is separate
from noise/interference acceptance, not permission to rescale a failure away.

The core is intentionally a **low-impedance calibrated bench target**, not all
possible sources. Also characterize 100k/100k and 1k/100k with reversed legs,
plus fixture capacitance/mismatch excursions. These are **stress cases outside
E1 acceptance**, not omitted failures or qualification of high-impedance use.
Publish their actual curves/exceedances. Extending the supported range needs an
explicit requirement revision before claiming success; do not relabel a failed
E1 case as stress after seeing its result.

### Defined aggressors and allocations, in peak units

| Class at its actual node | Declared envelope | Allocation per victim/frequency |
|---|---|---:|
| Other input channels | Up to THREE simultaneous unwanted channels, each at most 10 mV peak, measured at the relevant J2 node; test CH2N -> CH3/CH4 and reciprocal directions, all E1 terminations | **0.20 uV peak total**, not 0.20 per crossing or aggressor |
| AVDD | At most 1 mV peak per test tone, measured on AVDD AFTER the feed resistor; sweep around a compliant DC rail without exceeding its operating range | **0.10 uV peak** including internal PSRR and shared paths, not geometry alone |
| Common mode | 10 mV peak applied equally to each victim's two source legs; test matched E1 sources at 50/60 Hz as well as band checkpoints | **0.10 uV peak** differential |
| Digital/console | Existing 3.3-V nominal, 1-MHz SPI bursts and UART acquisition traffic, Wi-Fi/BLE off; compare quiet/normal and supported worst-toggle patterns after fixture review | **0.10 uV peak** aggregate activity-correlated response; don't assign an invented pin edge rate |

For a class with multiple aggressors, use
`sum_j((abs(Hij) + U95_Hij) * Aj) + U95_fixture <= allocation`.
For simultaneous classes sum their upper error bounds; the allocations add to
0.50 uV peak. Unknown phases must not be credited with cancellation. Residual
fixture feedthrough must be measured, conservatively retained or bounded; do
not subtract an unmeasured blank. A floor-limited result is **inconclusive**,
not a zero transfer. DC gain/offset and broadband noise need their own checks.

Use actual node amplitudes, not unloaded generator settings. In-band checkpoints
are 1, 5, 10, 20, 40 Hz plus 50/60-Hz diagnostics. Out-of-band spot tests must also
meet the same class allocation for any component appearing in 1-40 Hz: use
`fs_actual +/- {1,10,40}` and `2*fs_actual +/- {1,10,40}`; include 1 kHz, then
`fMOD_actual +/- {1,10,40}` with `fMOD_actual=4096*fs_actual` in the existing mode.
Input tones remain 10 mV peak; AVDD perturbations remain 1 mV peak. These are
finite spot tests, **not continuous-frequency RF immunity or an accepted bound
on all real spectra**. Missing instrumentation leaves the corresponding test
open. Record actual rise/fall times, ringing and harmonics at the AFE header;
unsupported patterns or injected rail noise must not bypass interface/startup
limits. A 1-MHz clock setting does not characterize its edges.

Sinc3 notches cannot be used to assume zero aliases: internal-clock tolerance,
frequency drift and response repetition near the modulator frequency matter.
TI specifies `fMOD=fCLK/2`, **1.024 MHz nominal**, and decimation 4096 at 250 SPS
[5, pp25-26,46]. The published upstream model does not implement silicon,
digital filtering or aliasing; evaluate those with the raw recorded result.

## 3. Measurement floor and feasibility, not available-equipment claims

Require total expanded uncertainty **U95 <=0.03 uV peak** on each reported
class-level coherent bound, including source calibration, fitting/repeatability,
fixture feedthrough and clock error. For RMS noise require **U95 <=0.05 uV RMS**;
accept only `estimate + U95 <= limit`. Retain a traceable calibration record,
raw samples and PSD normalization/ENBW. For noise use a declared one-sided PSD
integral over 1-40 Hz; remove DC/linear trend only, not in-band tones. For tones
fit sine/cosine at the actual frequency with repeated drive-off/on and reversed
polarity runs. Do not average magnitudes into a fictitious zero-floor result.

As a feasibility calculation only, 0.5-uV independent white sample noise and
16000 samples gives `1.96*0.5*sqrt(2/16000)=0.01096 uV` for a phase-referenced
sine coefficient. ADC filtering correlates samples; systematic feedthrough
and unknown-phase magnitude confidence are not included. Thus this does NOT
establish the 0.03-uV floor: demonstrate it with repeated blanks and actual
uncertainty analysis, or hold the test. A normal oscilloscope trace is not a
sub-microvolt coupling measurement. A calibrated attenuator/low-noise source
and verified capture/analysis chain are required; none is selected, owned or
priced by this slice. The $100 extra-parts objective is not an instrumentation
budget or a delivered quote.

## 4. Consistency calculations and what they cannot establish

At 303.15 K, the simple unfiltered thermal estimate
`sqrt(4*k*T*2*(Rs+4990)*39)` is **0.08844 / 0.13991 / 0.37027 uV RMS** for
Rs=1k/10k/100k per leg. It is the resistor contribution only and ignores
attenuation, excess noise and correlations. TI's gain-24/250-SPS table gives
**0.14 uV RMS at 65-Hz -3-dB bandwidth** under its stated conditions [5,p17];
that is not a whole-board maximum. These scales motivate the E1 target and
separate high-Z stress case; they do not predict a passing prototype.

The normalized nominal sinc3 magnitude at 40 Hz is **0.880371**, so requiring
flat response there would be incorrect. With the selected differential R/C
and E1's 10k sources, the simplified passive-times-sinc3 response is **0.879819**
relative to DC, before AFE parasitics. Full-scale is nominal +/-187.5 mV;
for 60-mV maximum differential magnitude and AVDD=4.75 V, TI's PGA headroom
inequality gives `0.92 < Vcm < 3.83 V` [5,p23]. E1's 2.40-2.60-V envelope is
inside it, but this does not replace startup, clipping or actual-rail checks.

The prior restricted mutual-C example was rerun at 1k/10k/100k with an ASSUMED
1 pF. At 60 Hz with a stiff 10-mV-peak aggressor it gives respectively
**0.003769 / 0.037645 / 0.352868 uV peak** before the ADC. The 1T-ohm/100-pF
load is still that hypothetical example, **not the actual E1 load**. Three
parameter cases plus native reversed/balanced/zero controls are six unique
native cases (the 10k case was also repeated). A separately assembled four-node
KCL matrix agreed at723 parameter/frequency points. No geometry-to-pF mapping,
noise certification or added project tests is implied.

For scale only, assigning one third of the 0.20-uV channel budget to each of
three 10-mV aggressors gives conditional assumed-C thresholds **1.771 pF at10k**
and **0.1889 pF at100k**, evaluated at integer frequencies1-60Hz with the SAME
restricted model and no uncertainty allowance. These are NOT bounds on actual
capacitance or compliance. They explain why accepting high-Z performance from
crossing counts or a nominal stack thickness would be unjustified.

The second executable block below repeats the six native cases, independent
matrix check and the conditional-C bisection using the exact published `simulate` and `predicted` definitions
from `REV_A_UPSTREAM_COUPLING_DISPOSITION.md`. It imports only those definitions
and imports, not that earlier example's top-level cases, and verifies its source
hash first. This changes experiment inputs, not the model or repository defaults.

The checkpoint JSON records numerical results, source locations and unconfirmed
fields. The first block derives both stack sums, code scale, headroom, thermal
and filter values, and the illustrative white-noise sine-fit estimate. The
second derives conditional-C limits by an 80-iteration bracketed search and
challenges both sides, as well as repeating the native/KCL checks. Both compare
derived quantities against their retained records; low-level floating residuals
are printed and bounded, not required to match bit-for-bit across toolchains.
Neither block verifies live manufacturer data or physical performance.

Review comment4145311992 identified missing derivations in the first published
examples. Two disposable incorrect-snapshot probes (doubled LSB and conditional-C
limit) were silently accepted before correction and are rejected by these
blocks. They are software/data probes, not native circuit faults or new project
tests. The corrected exact blocks then completed the actual calculations and
six unique native cases again, without changing the requirements or PCB.

Follow-up4145477875 found that the nominal code-scale expression disagreed with
TI Equation8 and the existing `ADCConfig.lsb_v` contract. A direct comparison
failed before correction. The prose, derived value and checkpoint now use
`Vref/(gain*2^23)`, or22.351741790771484nV/code for4.5V/gain24; the first block
also checks agreement with the existing API. No production conversion changed.

```python
import json
import math
from pathlib import Path
from lab.adc import ADCConfig

p = json.loads(Path("hardware/rev_a/board_profile.json").read_text())
checkpoint = json.loads(Path("docs/checkpoints/20260930_stackup_bench_envelope.json").read_text())
saved = checkpoint["analysis"]
assert (p["afe"]["gain"], p["afe"]["sample_rate_sps"]) == (24, 250)
assert not any(p["gates"].values()) and not p["afe"]["external_dummy_mode_enabled"]
assert p["input_network"]["series_resistance_each_ohm"] == 4990
assert p["input_network"]["differential_capacitance_f"] == 4.7e-9
fs, n = 250, 4096
fmod = p["afe"]["clock_hz_nominal"] / 2
assert fmod == fs * n
sinc40 = abs(math.sin(math.pi * 40 / fs) / (n * math.sin(math.pi * 40 / fmod))) ** 3
rows = []
for rs in (1000, 10000, 100000):
    resistance = 2 * (rs + 4990)
    pole = 1 / (2 * math.pi * resistance * 4.7e-9)
    rows.append(
        {
            "Rs_ohm_each": rs,
            "thermal_unfiltered_1_40_uVrms": math.sqrt(4 * 1.380649e-23 * 303.15 * resistance * 39)
            * 1e6,
            "pole_Hz": pole,
            "sinc3_40Hz": sinc40,
            "passive_times_sinc3_40Hz": sinc40 / math.sqrt(1 + (40 / pole) ** 2),
        }
    )
selected = sum([0.035, 0.2104, 0.0152, 1.065, 0.0152, 0.2104, 0.035])
comparison = sum([0.035, 0.0994, 0.0152, 1.265, 0.0152, 0.0994, 0.035])
gain, reference, max_diff = p["afe"]["gain"], p["afe"]["reference_v"], 0.060
headroom = [0.2 + gain * max_diff / 2, 4.75 - 0.2 - gain * max_diff / 2]
chosen_cm = [2.40, 2.60]
assert headroom[0] < chosen_cm[0] < chosen_cm[1] < headroom[1]
assert max_diff < reference / gain
calculated = {
    "selected_nominal_stack_sum_mm": selected,
    "comparison_3313_sum_mm": comparison,
    "full_scale_peak_V": reference / gain,
    "LSB_nV": reference / (gain * 2**23) * 1e9,
    "max_diff_V": max_diff,
    "common_mode_allowed_at_min_rail_V": headroom,
    "selected_instantaneous_CM_V": chosen_cm,
    "white_independent_sine_fit_95_uV": 1.96 * 0.5 * math.sqrt(2 / (64 * fs)),
}
# Equation 8 must also match the established project's code-to-volts contract.
adc = ADCConfig(gain=gain, vref_v=reference, fs_hz=fs)
assert math.isclose(calculated["LSB_nV"], adc.lsb_v * 1e9, rel_tol=1e-12, abs_tol=0)
# Derived numbers are computed above independently of the retained result values.
for key, value in calculated.items():
    actual_values = value if isinstance(value, list) else [value]
    saved_values = saved[key] if isinstance(saved[key], list) else [saved[key]]
    assert len(actual_values) == len(saved_values)
    assert all(
        math.isclose(a, b, rel_tol=1e-12, abs_tol=1e-12)
        for a, b in zip(actual_values, saved_values)
    ), key
assert len(rows) == len(saved["source_rows"]) == 3
for actual, retained in zip(rows, saved["source_rows"]):
    for key, value in actual.items():
        assert math.isclose(value, retained[key], rel_tol=1e-12, abs_tol=1e-12), key
allocations = checkpoint["bench_target"]["aggressor_allocations"]
assert math.isclose(sum(a["total_budget_uV_peak"] for a in allocations), 0.5)
print(json.dumps({"derived": calculated, "source_rows": rows}, indent=2))
```

Native/KCL reproduction (requires the declared locked environment and ngspice):

```python
import ast
import hashlib
import json
import math
import re
from pathlib import Path
import numpy as np

text = Path("docs/REV_A_UPSTREAM_COUPLING_DISPOSITION.md").read_text()
match = re.search(r"```python\n(.*?)\n```", text, re.S)
assert match is not None
code = match.group(1)
assert (
    hashlib.sha256(code.encode()).hexdigest()
    == "b87d7c32e9cb3f648c52b74038c82280807aa5c91300825bf91b037e2bf6b5fa"
)
module = ast.parse(code)
definitions = [
    node for node in module.body if isinstance(node, (ast.Import, ast.ImportFrom, ast.FunctionDef))
]
namespace = {}
exec(compile(ast.Module(body=definitions, type_ignores=[]), "<reviewed model>", "exec"), namespace)
simulate, predicted = namespace["simulate"], namespace["predicted"]
checkpoint = json.loads(Path("docs/checkpoints/20260930_stackup_bench_envelope.json").read_text())
saved = checkpoint["analysis"]
rows, matrix_errors = [], []
for rs in (1000.0, 10000.0, 100000.0):
    frequency, native = simulate(rs, 1e-12, "p")
    error = max(abs(h - predicted(f, rs, 1e-12)) for f, h in zip(frequency, native))
    assert len(frequency) == len(native) == 241 and error < 2e-14
    for f in frequency:
        s, g, ys = 2j * math.pi * f, 1 / 4990, 1 / rs
        yc, yd, m = 1e-12 + s * 100e-12, s * 4.7e-9, s * 1e-12
        # Independent four-node KCL, order upstream P,N and filtered P,N.
        a = np.array(
            [
                [ys + g + m, 0, -g, 0],
                [0, ys + g, 0, -g],
                [-g, 0, g + yc + yd, -yd],
                [0, -g, -yd, g + yc + yd],
            ],
            dtype=complex,
        )
        v = np.linalg.solve(a, np.array([m, 0, 0, 0], dtype=complex))
        matrix_errors.append(float(abs(v[2] - v[3] - predicted(f, rs, 1e-12))))
    rows.append(
        {
            "Rs_ohm_each": rs,
            "native_error_V_per_V": error,
            "calculated_uV_at60Hz_10mV_peak": abs(predicted(60, rs, 1e-12)) * 1e4,
        }
    )
f, positive = simulate(10000.0, 1e-12, "p")  # Deliberate repeat, not a new unique case.
controls = {}
for mode in ("n", "balanced", "none"):
    f2, h2 = simulate(10000.0, 1e-12, mode)
    assert f2 == f and len(h2) == len(positive)
    expected = [-h for h in positive] if mode == "n" else [0j] * len(positive)
    controls[mode] = max(abs(a - b) for a, b in zip(h2, expected))
    assert controls[mode] < 2e-14
assert len(matrix_errors) == saved["independent_matrix_points"] == 723
assert max(matrix_errors) < 2e-14
assert len(rows) == len(saved["source_rows"]) == 3
for actual, retained in zip(rows, saved["source_rows"]):
    assert actual["Rs_ohm_each"] == retained["Rs_ohm_each"]
    assert math.isclose(
        actual["calculated_uV_at60Hz_10mV_peak"],
        retained["one_pF_10mV_peak_at60Hz_uV"],
        rel_tol=1e-10,
    )
# Residuals are numerical observations, not bitwise-portable reference outputs.
assert all(v < 2e-14 for v in controls.values())

# Solve the restricted model's single-pair limit, NOT an extracted PCB bound.
# The channel class has 0.20 uV peak total / 3 simultaneous 10-mV aggressors.
frequencies = range(1, 61)
budget_V, aggressor_V = 0.20e-6 / 3, 0.01
limits = []
for rs in (10000.0, 100000.0):

    def response(cm):
        return max(abs(predicted(hz, rs, cm)) * aggressor_V for hz in frequencies)

    lo, hi = 0.0, 100e-12
    assert response(lo) <= budget_V < response(hi)
    for _ in range(80):
        mid = (lo + hi) / 2
        if response(mid) <= budget_V:
            lo = mid
        else:
            hi = mid
    assert hi - lo < 1e-24
    # Challenge both sides of the computed crossing, not only a retained number.
    assert response(lo * 0.99) < budget_V < response(lo * 1.01)
    limits.append(
        {
            "Rs_ohm_each": rs,
            "conditional_Cm_pF": lo * 1e12,
            "allocation_peak_uV_per_pair": budget_V * 1e6,
            "tested_integer_frequencies_Hz": [1, 60],
            "uncertainty_allowance_included": False,
        }
    )
assert len(limits) == len(saved["conditional_cap_limits"]) == 2
for actual, retained in zip(limits, saved["conditional_cap_limits"]):
    for key in ("Rs_ohm_each", "conditional_Cm_pF", "allocation_peak_uV_per_pair"):
        assert math.isclose(actual[key], retained[key], rel_tol=1e-10, abs_tol=1e-12), key
    assert actual["tested_integer_frequencies_Hz"] == retained["tested_integer_frequencies_Hz"]
    assert retained["uncertainty_allowance_included"] is False
assert saved["native_runs_unique"] == 6 and saved["native_executions"] == 7
print(
    json.dumps(
        {
            "rows": rows,
            "conditional_cap_limits": limits,
            "controls": controls,
            "matrix_max_error_V_per_V": max(matrix_errors),
            "unique_native_cases": 6,
            "native_executions": 7,
        },
        indent=2,
    )
)
```

## 5. Exit and next action

The **design target is selected; the factory stack is not yet released**. Keep
the nine-location coupling group OPEN for the confirmed geometry and E1 result.
A pilot risk review may recommend retaining that copper for the LIMITED E1
experiment, but this document does not make that release decision or widen E1
into electrode/high-Z qualification. E1 failure, unresolved fixture floor or
unacceptable confirmed geometry triggers a combined rework/review, not nine
automatic edits. Existing targeted layout guards stay active.

Next independently actionable source work is **#48 capacitor lifecycle and
effective-capacitance closure**, while the prepared factory/fixture questions
remain on #45. Do not spend another slice merely restating undefined inputs:
use E1 and the named target. If a vendor response is unavailable, retain the
specific unknown tolerance fields and continue other finite design decisions;
never report them confirmed. Actual fixture design, firmware external-mode
review and physical tests follow their existing gates. No order, purchase,
fabrication, powered connection or body use is authorized.

## Primary references checked on 2026-09-30

[1] JLCPCB named stackups, 1.6mm/1oz/0.5oz table:
https://jlcpcb.com/impedance
[2] JLCPCB calculator guide (page states updated Sep16,2026), material and
calculation parameters: https://jlcpcb.com/help/article/user-guide-to-the-jlcpcb-impedance-calculator
[3] JLCPCB laminated structures (page states updated Apr24,2025), pressed versus
raw thickness and finished copper: https://jlcpcb.com/help/article/multi-layer-pcb-standard-laminated-structures
[4] JLCPCB rigid capabilities, thickness/trace/hole constraints:
https://jlcpcb.com/capabilities/pcb-capabilities/
[5] TI ADS1299-x SBAS499C, pp9,17,23,25-26,38,46 (tables/equations inspected as page
images): https://www.ti.com/lit/ds/symlink/ads1299.pdf

The stack page has no immutable revision/commit identifier. Its inspected
values and contradictions are retained in the checkpoint, not represented as
a dated factory drawing. Only public primary sources were used for technical
facts. Source-only changes in this PR require their own exact-head CI/review;
baseline and analysis passes do not validate a later head.

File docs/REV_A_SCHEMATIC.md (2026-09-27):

# Rev A native schematic: review candidate, not a released board

The editable source is `hardware/rev_a/kicad/rev_a.kicad_sch` with two child
sheets, `power.kicad_sch` and `digital.kicad_sch`. Open that root in KiCad.
`RevA.kicad_sym` is the project-local, three-unit ADS1299-4 symbol and small
support library. No generator, SKiDL, KiBot, IPC service or new Python dependency
is needed to edit or check the circuit. All 64 ADS package pins are explicit.

## Scope and decisions

The three sheets contain 69 BOM component instances, including the off-board
ESP32-S3 devkit and eight DNP diode packages. There are 68 daughterboard
footprints, of which 60 are fitted in this candidate. U1's three drawn units are
one physical ADS1299-4. The controller is explicitly excluded from the PCB and
has logical GPIO identifiers, **not** a mechanically validated devkit footprint
or physical header-pad map. Its 5 V and ground show the intended external bench
harness; simultaneous USB power remains prohibited.

The selected part families and firmware are unchanged. The one scoped BOM
correction removes `R_DAISY_DN`: TI's unused-input rule calls for DAISY_IN pad 41
to connect directly to DGND. CLK pad 37 retains its own 10 kOhm pulldown. Unused
SRB1/SRB2 are explicitly NC, one of the alternatives permitted by the datasheet;
no ERC pin-conflict suppression is used to justify grounding bidirectional pins.
BIASIN/BIASREF return to ground, while the existing local 1 MOhm || 1.5 nF BIAS
feedback and separate 1 MOhm dummy-output resistor remain. BIAS stays disabled.

The 100 uF VCAP1 and 22 uF reference capacitors retain their selected tantalum
packages and explicit positive pad 1. **VREFP does not connect to DVDD**: its
capacitors return to VREFN/AVSS. The differential 4.7 nF input capacitors bridge
the two post-resistor ADC inputs, not ground. DNP BAV199 pin 1 is the lower-rail
anode, pin 2 the upper-rail cathode and pin 3 the input junction. DNP footprints
are not qualified protection. The TPS7A2033PDBVR uses the DBV pinout, with EN tied
to IN and NC pad 4 left unconnected; this regulator supplies only ADS DVDD.

Native reference designators are conventional R1/C1/etc. Each component carries
a `ContractRef` field that preserves the existing functional BOM reference, such
as `R_CLK_DN`. The checker requires a bijection, matching quantities, MPN, value,
tolerance, footprint, and independent native DNP/on-board flags. This adapter is
not a second BOM. The retained CSV includes both reference names.

## Reproduce the native check

The Linux reference environment pins KiCad **9.0.2**, Debian package
`9.0.2+dfsg-1`, and footprint/symbol packages `9.0.2-1`. This is the tested
reproducibility pin, not a claim that it is the newest KiCad release. The exact
container and Actions revisions are in `.github/workflows/schematic.yml`.

```sh
uv sync --locked --all-extras
uv run --locked python -m tools.check --schematic --out reports/schematic
```

`KICAD9_FOOTPRINT_DIR` may select the installed pinned footprint directory; the
Linux default is `/usr/share/kicad/footprints`. The same gate runs in CI, checking
out the explicit PR head. It first runs the ordinary checks, then requires the
actual CLI, full-severity ERC JSON, a fresh KiCad XML netlist, project connectivity
checks, PDF/CSV exports, CSV-to-XML inventory validation and the native CAD
regression tests. Native commands pin `LC_ALL=C` and `LANG=C` so exported flag
labels do not depend on the operator's desktop language. A version string
alone is never execution evidence. Each run has a fresh output directory and an
isolated `KICAD_CONFIG_HOME`. Missing tools/artifacts, failed loads, violations,
partial reports, regression failures or changed input hashes fail the request.

The success marker is invalidated before even the ordinary checks.
`SCHEMATIC_CHECK.json` records commit, dirty-worktree status, all declared native
files, selected installed footprint files, checker/baseline hashes, artifact
hashes and counts. A dirty local run is not represented as exact-commit evidence.
The file inventory is deliberately closed: adding a child sheet or external
symbol library requires updating and reviewing the dependency contract. Library
names must match their own URIs, not merely an independent allowed set. No ERC
exclusions or severity overrides are accepted in this candidate.

## Tests and their limits

Ordinary tests use a compressed, frozen native XML export solely as a fixture.
The native suite regenerates the graph and compares it to that fixture. It also
exports six deliberately broken native source variants and checks rejection.
Wrong resistor values and fitted optional clamps still pass general ERC, but
fail the project-specific checker. An all-sheet net rename remains acceptable.

The graph fault sweep moves each of 256 terminals to every other existing net:
14,592 rejected changes. It also rejects all missing components/terminals and
polarized-capacitor reversals, while accepting 54 nonpolar passive reversals and
net renaming. These are finite connectivity-fault tests, **not** a claim of
exhaustive electrical fault coverage or a code-mutation score. Source/report
fault fixtures challenge missing caches/libraries, external/nested dependencies,
symlinks, FIFO/oversize inputs, malformed XML, stale success markers and partial
or suppressed ERC reports. Process doubles never count as native CAD evidence.

The checker encodes the selected topology with independent datasheet pad numbers;
it does not infer correctness from net-label spelling or a reference board's
unreviewed drawing. Its closed component/pin inventory makes unintended extra
connections and apparently plausible wrong rails visible before layout.

## Review corrections: BOM export and symbol-cache agreement

A clean graph is not enough to approve its accompanying review artifacts. The
first independent review found two gaps, reproduced before correction:

- A component marked `in_bom no` still appears in the XML and passes the topology
  contract, but disappears from the native CSV. The gate now parses the CSV and
  requires each of the 69 validated XML components exactly once, with matching
  native/contract references, value, MPN, footprint, population, DNP and off-board
  flags. Missing, duplicated, grouped, unknown or changed rows fail. Eight DNP
  parts and the off-board controller must remain visible; this is a review BOM,
  not an assembly release. CSV row/header order, quoting and blank lines are
  immaterial. The expected inventory comes from the already-validated XML, not
  another manually maintained component list.
- KiCad exports the embedded definitions in each sheet. Editing only the local
  ADS library can therefore leave ERC and the graph unchanged while a later
  library update would alter the design. Before exporting, the gate now compares
  each used embedded definition against `RevA.kicad_sym`, ignoring whitespace
  and only the embedded root identifier's `RevA:` prefix. The small, read-only
  token-tree comparison checks full symbol bodies, duplicate definitions, the
  cache/placed-instance inventory and bounded structure. It neither edits CAD
  nor replaces KiCad's semantic parser. Symbol inheritance is unsupported, and
  body reordering or alternate numeric spellings are conservatively rejected;
  synchronize definitions explicitly rather than adding a suppression.

Seven original regression probes failed before the fixes (five library-only
changes and two invalid CSV outputs). Additional fixtures remove every CSV row,
corrupt each exported field and challenge malformed syntax and cache inventory.
Benign synchronized symbol edits, definition ordering and outside-string
whitespace remain accepted; the checker is not a fixed source-hash allowlist.

Two real KiCad cases demonstrate why both new checks are needed: an excluded
resistor and a library-only ADC pin rename each produce zero ERC violations and
pass the existing XML graph contract, then fail the relevant new check. The
canonical native case also verifies the newly exported CSV. Together with the
existing eight native cases, these form ten actual KiCad regression cases;
software-only token/process fixtures are not counted as native execution.

## Still blocked

All hardware/firmware-port review, schematic release, purchasing and body-use
gates remain false. ERC and connectivity tests do not settle boot-ROM GPIO
behavior, brownout/back-powering, the passive analog startup fixture, effective
capacitance, leakage, real noise or BIAS stability. The existing operator
acknowledgments are not sensing/interlocks. No PCB or physical measurement was
created by this slice. Footprint identifiers are assigned, but independent
package dimensions, pin-one orientation, polarity and layout review remain next.
Then come PCB layout/DRC and schematic parity, delivered quotes, and staged
person-disconnected bench bring-up. TPS7A20 reference-engine work remains parallel.

## Primary basis

- TI ADS1299 SBAS499C: pin tables, section 10.1.1, power/reference and startup.
  https://www.ti.com/lit/ds/symlink/ads1299.pdf
- TI TPS7A20 SBVS338H: DBV pin table and section 6.3.2 EN connection.
  https://www.ti.com/lit/ds/symlink/tps7a20.pdf
- Nexperia BAV199, 1 April 2023: series-pair pinning (1=A1, 2=K2, 3=K1/A2).
  https://assets.nexperia.com/documents/data-sheet/BAV199.pdf
- KiCad 9 CLI and environment documentation: ERC JSON, XML, PDF, CSV, config.
  https://docs.kicad.org/9.0/en/cli/cli.html
  https://docs.kicad.org/9.0/en/kicad/kicad.html

External research was treated as questions to verify, not a replacement circuit
specification. In particular its VREFP-to-3.3-V recommendation was not adopted.

## Physical harness continuation

The native gate additionally derives `harness.json` from the freshly checked
XML/profile/BOM and the explicit firmware console header. It gives qualified
AFE/DevKit header-pad identities, all20 J_DIG contacts, separate application
UART RX17/TX18 and common supply/return groups. The 43-input snapshot binds
the new derivation, route-defining firmware and executed host oracle; the five retained artifacts include this
worksheet. Standalone schematic checks require g++/clang++ and execute the
existing focused sketch/CDC tests before publishing the harness. Historical
counts above describe their earlier source revisions.
See `REV_A_BENCH_HARNESS.md`: these are document-derived endpoints, not a
qualified cable or interface. The CAD source and its logical MOD1 remain unchanged.

## Local T491 land selection

C_REF and C_VCAP1 now select the two native project-local RevA_Passives
footprints described in `REV_A_TANTALUM_LANDS.md`. The seven existing top-level
CAD files plus two local footprint files are always snapshotted; seven other
selected definitions remain in the installed library. The full gate still
hashes44 inputs. Only these two footprint IDs change in the fresh XML/CSV
fixtures; electrical connectivity, MPNs and all false approval gates remain.
This is a nominal reflow design choice, not an assembled-board qualification.

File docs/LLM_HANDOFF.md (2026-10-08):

# Continue from L4: implement five accessible SPI series positions; no trace-surgery fallback

**Read `REPOSITORY_PUBLICATION.md` before GitHub publication or recovery.**
Read root `AGENTS.md`, `DEVELOPMENT.md` and `REV_A_BENCH_FIRST.md`. Start with
live main, open AND recently merged PRs and original review threads. Missing
chat replies have followed successful merges. Do not recreate their work.
Source publication, Codex review, CI and merge are different operations.

## Current source and next practical task

B2 merged in PR92 at `8c08e012e58b9bde7ca2b0f3df9c0126d10b0c00`, tree
`7e7322374c84b58704f0d30388f458e165bfea2a`. B1/PR91 and Q1/PR89 are already
merged, as are capacitor/S1-S4/P3/R1/C1-C4/F1/K2 decisions. PR90 is a closed
competing RFQ; never revive `quote_draft/`. B3 merged in PR93 at
`2a5d0e60cc823ffdfbea5d0c45164b6b648deb6c`, tree
`ed83eefb7d2286214d3a38dbea98a1c703491892`. L1 merged in PR94 at
`9af4a71c1f2895d4c9e8517ffae3f2cb58f26bd5`, tree
`42c3e2a08a2bf50ece59038a1ce997ec7cd02c26`. L2 merged in PR95 at
`ea853b338ebe6b79f01d283244eec77faebc64f4`, tree
`df5b2668f8aca78754d71c1207e97634317ae0c0`. L3 merged in PR96 at
`cc89a5b9cbdcdbd975109f75dd4a9d0587286384`, tree
`a211a23296f9981429dd162cf1501dfe1c7b5968`. Check live PR/main status for L4.

Read **`REV_A_CONTACT_ACCESS_B3.md`** and its small read-only
`studies/b3_access_envelope.scad`. The existing K2 ribbon blocks a straight
approach to C30; its guide blocks C33. Prefer five separately identified,
insulated fine-wire sense pairs on C6/C30-C33 with independently supported
outboard relief, rather than clips under the cable. No board/header/holder
redesign or general pogo fixture is justified by the nominal clearance study.
The SCAD imports current K2 and models routing SPACE, not actual wire joints,
clamps, populated PCB bodies, qualified probe hardware or printable parts.

Native OpenSCAD intersections detect both blocked approaches and a deliberately
raised bad corridor. The proposed z=5.5 mm aerial corridors avoid the retained
K2 envelopes; they do NOT qualify the local solder exits, installed insulation,
sag/strain, tolerances, removal motion or measurement response. A 4 mm component
allocation and bare pad dimensions are not real exposed-metal/clearance evidence.
Actual wire/attachment process, joint inspection and restraints remain before-use
requirements. Separate negative sense conductors must not become an external
common ground bus, power return or unreviewed instrument-earth connection.

**L1 return-edge triage:** read `REV_A_PILOT_RETURN_DISPOSITION_L1.md` and
`studies/l1_return_triage.json`. The 20 historical envelope records are not
20 present defects: 19 are active in the planar check, two duplicate one
RAILS_OK location, and the old y=35 TARGET_VIN5 outline disappeared after R1.
The native count remains 18 affected tracks. Active residuals lie at other-net
via-clearance edges, not own-net exclusions; nominal penetration is 0.5 to
6.1901 um, NOT a fabrication tolerance, loop length or noise bound. Keep the
pending fixture and all guards unchanged. No mandatory reroute is established
solely to erase this counter, and no blanket extra ground-via rule is justified:
all 118 non-ground auxiliary vias join F/In2 about the same domain's In1 plane.
This retains copper for design/DFM continuation, NOT manufacture or electrical
acceptance. Real antipad/terminal/channel and stackup decisions are not waived.

**L2 complete-channel protocol/timing review:** read `REV_A_SPI_CHANNEL_L2.md`.
Keep the existing 1 MHz, MSB-first mode1 and command delays. The actual pinned
Arduino3.3.12 path programs mode1 and clocks eight-bit hardware transfers; it
is not ESP-IDF's per-device input-delay/dummy-cycle driver. The ADC launches
DOUT following rising SCLK; the logical MCU receive edge is falling, not the
C++ return event. Do not add dummy clocks, switch modes or slow SPI merely
because there is a cable. All hardware and actual firmware gates stay unchanged.

L2 maps four complete signal paths and separates setup, hold, command guards
and whole-frame timing. The conditional 11+17+11=39 ns subtotal uses the TXU
5 pF propagation test, NOT S2's assumed100pF or the actual cable. The ideal
500-39=461ns remainder is NOT qualified margin. Actual load/interconnect/MCU
aperture and monotonic receiver edges remain required; no numeric resistor is
selected and no termination waiver follows. Pulldowns are not source damping.
The source guard3us versus4*666ns gives336ns before uncertainty/skew, not a
measured receiver-local pass. 120clock-us per nominal4ms excludes software gaps;
status/DRDY checks are not a CRC or complete physical-edge guarantee.

**L3 decision:** read `REV_A_ANALOG_PILOT_L3.md`. Retain the six upstream
net-pair geometries for a proposed INTERNAL-TEST-ONLY first pilot rather than
reroute them now. All nine current locations were rechecked. This closes the
choice of pilot proposal, not manufacturing approval or external performance.
The release decision must explicitly accept the restricted purpose and the
possibility of another PCB revision before E1; no order or gate is authorized.
The existing 0x65/MUX101 internal test bypasses normal external selection; the
0x61/MUX001 alternative is internal short, NOT an external acquisition mode.
B1 remains required, BIAS/lead-off/SRB remain off. Mux switches do not isolate
pins from electrical damage or eliminate supply/package/parasitic coupling.
E1's external-source, noise, coherent-error and uncertainty limits stay intact.
Never claim that internal-test success qualifies the external R/C/channel path.

**L4 provision decision:** read `REV_A_SPI_PROVISION_L4.md`. Choose five
accessible series-component positions in the next custom-board revision, not
cut-and-flywire rework: AUX R117/U102.13 SCLK, R118/U102.12 MOSI,
R119/U102.11 CS, R120/U102.5 MCU-side MISO, and AFE R24/U1.43 DOUT.
These are proposed unused references, NOT implemented footprints or selected
nonzero resistor values. Four launches go into the nominal F.Fab body box
before their first via. R114 is a shunt pulldown and must stay receiver-side of
R120; replacing it with a small resistor would load MISO toward ground.
Prefer accessible existing-family 0603 lands with short driver-side routing;
final placement/parts/process still need native and physical-access review.
No parallel bypass: absent component means open, unlike a fitted 0-ohm link.
Zero ohms may represent an unpowered continuity baseline, never automatic
first-power/damping approval. No chip lifting, hidden cuts or aerial logic wires.

**Next source task:** implement these five series positions coherently across
schematics/BOM/PCB/contracts/fixtures, with failing split-net/path checks first,
native parity/refill/cut-track checks and independent review. Preserve unaffected
copper and all reference/domain/bypass guards; scope any necessary local change
explicitly. Do not write another generic rework/timing plan in place of this edit.
The three MCU-driven segments remain separate, not fixed by parts after U102;
no resistor at AUX J102 is automatically source termination at the DevKit.
DRDY/other control-channel requirements are not waived or silently added to the
five-site scope. Q1 is historical: record later accepted deltas without changing
its frozen input hashes. L1-L3/B1-B3, price searches and RFQ are not repeat tasks.

B1-B3 now define the intended startup fixture, observations and contact approach.
Do not add another generic measurement plan. Actual implementation/commissioning
must use B2's EXISTING run card: selected instruments, accepted sense-lead process,
connection/earth sketch, coverage, uncertainty, numeric ramp/current/thermal and
shutdown/discharge limits. No approved settings or measurements exist yet.

## Standing user direction

Delivery planning is **Moscow, Russia**; no postcode, supplier, delivery feasibility
or outreach permission is inferred. Avoid detailed price/stock research. Keep
Q1 at `REV_A_PILOT_QUOTE_PACKET.md` and `quote/` as the sole frozen unsent snapshot;
its 18 source and two schedule hashes remain unchanged. Active versus proposed
MPNs are intentionally different at 26 AFE ceramic sites, not applied substitutions.
No contact/order/production is implicit in "next". The historical USD94.84 is not
a delivered kit price or proof of the USD100 objective.

Use clearly labelled reversible assumptions to advance independent work. Plan
around an off-the-shelf regulated 5 V bench source with output enable/current
limiting, not a raw battery or custom charger. Available 1 A capacity is neither
measured consumption nor an initial current-limit setting. Do not block unrelated
build decisions on the missing instrument model or invent evidence to fill it.
Each slice closes a decision, repairs a demonstrated defect or prepares a specific
physical check. No new code framework or broad refactor without an actual need.

## Preserved engineering boundaries and authoritative detail

AFE authored PCB: `hardware/rev_a/layout/rev_a.kicad_pcb`, SHA256
`60097ff4acf8408d5a172930de74bcd36aa50a379dd30a831e4bc64d3841c8a6`.
Auxiliary: `hardware/rev_a/auxiliary/auxiliary.kicad_pro` and adjacent PCB.
Never run the parking-grid importer or old authoring helpers over either board.
Keep the 15 bypass corridors, 39 terminal-cut tests, domain/mounting guards and
18 pending reference records/20 outlines. The central 0.10 mm reference strip
and own-contact exclusions are not full-width ground, impedance or SI proof.

Read `REV_A_PILOT_CAPACITOR_DISPOSITION.md` and `REV_A_100NF_REUSE_DECISION.md`:
proposed 15 x 1 uF, four x 10 uF and seven AFE 100 nF replacements remain
unapplied; 15 auxiliary 100 nF and C0G/T491 remain selected. Internal VCAP3 is
boosted; typical curves, nominal values and body envelopes are not guaranteed
joint-corner capacitance, transient or mounted-height limits. Coordinated accepted
BOM/CAD/contracts/fixtures changes follow the applicable process/electrical
responses or explicit limited-pilot disposition, not isolated MPN edits.
AFE's named stack target is not factory approval or an approved auxiliary stack.

B1: J2-only keyed cable; contacts 1-8/10 common, BIAS9 and NC11-20 individually
isolated. Preserve pre-join identity because commoning hides permutations. J1 is
forbidden; reversed mis-mating can short its 5 V feed. Physical retention and
detached-passive test conditions remain unqualified; no generic assembled-IC
ohmmeter acceptance. C4: pins1/5 return,2 AFE DVDD OUT,3 separate DVDD sense,
4 AVDD sense after R11,6 empty. Feed/sense join only on AFE. No hot mating.

B2: capacitor contacts are landmarks, not all-chip-terminal voltage proof. Preserve
R -> fresh F1 arm -> wake/clock ->150 ms -> VCAP1 >1.1 V at V -> reset. Do not
demand raised VCAP1 with PWDN parked before R. BOARD_PROFILE_REVIEWED stays false;
the distributed onboard-UART stopped build is not the hypothetical reviewed
C1-header acquisition. Neither acknowledgment automatically measures voltage.
Both DevKit USB ports remain excluded with accessories; HOST/TARGET must not
be bridged by supply links, instruments, chargers or shields. STOP/polling is
not a power disconnect or guarantee against fast faults. Digital buffering does
not protect analog electrode inputs. Preserve complete-run fault invalidation.

S3's 21 physical input terms remain unknown; S4's conditional regulator/current
information is not an assembled-source qualification. Keep source/current/peak,
leakage, sense injection, partial-rail and ground-break conditions open for their
actual dependent stage. No powered protocol, external acquisition or person/
animal use is released. Keep #45/#48 and manufacturing/fixture requirements open.

## Verification and completion reporting

Use locked uv and the single `tools.check` gate, with unchanged 450 s CAD budget
and 71% branch floor. Retain installation/tool errors; do not use an unlocked
substitute as a pass. B3's seven native envelope cases are authoring diagnostics,
not additions to the project test totals or physical experiments. Inspect actual
exact-head CI and independent review before merge; read back main/tree afterward.

Report TLDR and category/remaining-turns/status/next-step roadmap. Distinguish
nominal source geometry, physical workmanship, instrument qualification and
release. Purchasing, fabrication, building/mating fixtures, powering, external
inputs and body connection are not authorized by a documentation/source merge.

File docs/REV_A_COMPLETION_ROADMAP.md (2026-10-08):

# Rev A roadmap - L4 selects series positions; next is the scoped CAD edit

L3 merged in PR96 at cc89a5b9; L1/L2, B1-B3 and the sole Q1 packet are retained.
L4 rejects routine trace-surgery fallback and selects five custom-board SPI
series positions. It does not add them, choose damping values or release hardware.
Read live main/open/recent PRs, AGENTS, REPOSITORY_PUBLICATION and the handoff.
Moscow remains the planning destination; detailed prices/outreach stay paused.

| Category | Remaining substantial turns | Done/status | Next slice or blocker |
|---|---:|---|---|
| SPI provision method | 0 for decision | Five positions identified; four source escapes enter nominal package body boxes | No claimed solder/rework qualification or fitted parts |
| Five-position implementation | 1-2 source turns | Exact driver/downstream boundaries and proposed refs in L4 | NEXT: coherent schematic/BOM/PCB/contracts edit with targeted failing tests and native review |
| Other digital-channel disposition | 1 bounded decision plus needed evidence | Three MCU-driven stages and DRDY/control paths explicitly separate | Actual source-end access/channel evidence or bounded pilot disposition; not solved by five pads |
| Analog pilot choice | 0 for proposal | L3 retains six upstream pairs for internal-test-only purpose | Explicit scope/revision-risk acceptance at release; E1 unchanged |
| Components / manufacturing | 1-2 plus required evidence | Existing candidates and Q1 process questions retained | Accepted stack/component/assembly decisions and coordinated changes |
| B1-B3 physical setup | Assembly/equipment-dependent | Existing plans and B2 run card, no new framework | Actual contacts, insulation, restraint, instruments and approved limits |
| Fabrication release | 1 after prerequisites | Not released; Q1 remains a frozen quote snapshot | Consistent revision, restricted purpose, remaining dispositions and order approval |
| First power / internal capture | Approved physical-work dependent | Firmware gate false, no acquisition | Inspected real assembly and measured commissioning under separate permission |
| Prices / RFQ | Paused | One canonical unsent packet | No duplicate packet or price/stock campaign |

Estimates overlap and exclude supplier/fabrication/shipping/physical time.
Five positions cover the custom-board SPI drivers, not every output in the
system. The three MCU launch segments and DRDY/control/fault behavior remain
subject to their own conditions. No universal resistor, source-impedance value,
loop/edge budget or first-power setting is inferred from nominal geometry.

Next implement AUX R117-R120 and AFE R24 as proposed in L4, not a further
paper provisioning exercise. Keep existing R114 on the receiver side, avoid
parallel bypasses and verify both sides of the added parts. No bare-IC lifting,
blind trace cuts, global footprint edits or enlarged reference allowances.
Keep the implementation separate from unrelated refactors and capacitor choices.
All #45/#48 and purchase/fabrication/rework/construction/mating/power/external-
acquisition/person or animal connection permissions remain unchanged.

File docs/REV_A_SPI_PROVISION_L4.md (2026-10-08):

# L4: provide replaceable SPI series positions; do not rely on trace surgery

2026-10-08. Inspected main `cc89a5b9cbdcdbd975109f75dd4a9d0587286384`,
tree `a211a23296f9981429dd162cf1501dfe1c7b5968` (L3 / PR96).

**Decision: include five accessible series-component positions in the next
custom-board revision, rather than accepting cut-and-flywire rework as the SPI
fallback.** Four are at U102 outputs on AUX, one at U1 DOUT on AFE. This is the
selected implementation requirement, NOT already-added footprints, a selected
damping value or permission to manufacture/power. It does not certify all eight
driver-to-receiver segments in L2. The three MCU-driven segments remain distinct.

The source evidence below makes the choice concrete: four of those five launches
enter the nominal package-body projection before their first via. The schematic
contains no existing series part in any of the five paths. R114 is a shunt
pulldown, not a spare series resistor. No chip lifting, hidden-track cutting,
long aerial digital jumpers or connector-only resistor workaround is accepted.

## 1. What the authored geometry actually allows

Coordinates are native board millimetres; do not mix AFE and AUX origins. The
inspection follows F.Cu centreline segments from each driver-pad centre to its
first same-net via, then compares against the footprint's transformed F.Fab
body bounding rectangle. This is NOT a microscope inspection, exposed-metal
measurement, maximum package envelope or new native clearance/DRC execution.

| Driver / net | First via centre (x,y), mm | Surface path to via, mm | Via inside nominal body box? |
|---|---|---:|---|
| AUX U102.13 / AFE_SCLK | (39.050,24.900) | 2.791 | No |
| AUX U102.12 / AFE_MOSI | (38.100,28.450) | 1.379 | Yes |
| AUX U102.11 / AFE_CS | (39.000,28.450) | 1.313 | Yes |
| AUX U102.5 / MCU_MISO | (39.600,31.550) | 1.352 | Yes |
| AFE U1.43 / MISO | (51.375,35.225) | 2.505 | Yes |

U102's nominal body box is x=36.5..41.5, y=27.8..32.2; U1's is x=43..53,
y=32..42. The MISO launch from U1 has about 1.842 mm of the listed surface path
inside that nominal body box. Its first source segment is UUID
`d62dab04-82cb-5c0b-9d6f-c901c9d73358`, and first via is
`ac44305d-37c6-52b6-bfd7-d78f6c407686`. U102 clock's first via is
`34b78612-00ef-54da-b5eb-b1e05db9b0fe`. These locate the analysis, NOT cut points.

U102 pads have 0.65 mm pitch and 0.40 mm transverse copper width; U1 has
0.50 mm pitch and 0.30 mm transverse width. The relevant tracks are only
0.20 mm (AUX) and 0.15 mm (AFE) wide. A visible front-layer segment is therefore
not automatically a supported, inspectable place to scrape solder mask and
bridge a resistor. Even the clock's outward escape has no designed series lands.
No conclusion that specialist rework is impossible is needed: no such accepted
process exists, and the pilot need not depend on it.

The existing resistor footprint is `Resistor_SMD:R_0603_1608Metric`: two
0.80 x 0.95 mm pads with 1.65 mm centre spacing and a 2.96 x 1.46 mm courtyard.
Use that as the first placement candidate, not the different capacitor land.
It cannot simply be dropped between adjacent IC leads. Route the chosen launches
out to accessible lands; check final part lands, reference coverage and tool/body
access. Exact placement and solder-process feasibility are not established here.

## 2. Exact proposed series boundaries (not active schematic edits)

References below were unused in the inspected source. They are proposed for the
next coherent CAD change, not purchased parts or new entries in the active BOM.
Pad 1 is the driver side by convention; the resistor is electrically nonpolar.

| Proposed position | Driver-side net / only intended endpoints | Existing downstream net / preserve these destinations |
|---|---|---|
| AUX R117 | AFE_SCLK_DRV: U102.13, R117.1 | AFE_SCLK: R117.2 -> J101.1 -> K1 -> AFE J1.1 -> U1.40 |
| AUX R118 | AFE_MOSI_DRV: U102.12, R118.1 | AFE_MOSI: R118.2 -> J101.3 -> K1 -> AFE J1.3 -> U1.34 |
| AUX R119 | AFE_CS_DRV: U102.11, R119.1 | AFE_CS: R119.2 -> J101.7 -> K1 -> AFE J1.7 -> U1.39 |
| AUX R120 | MCU_MISO_DRV: U102.5, R120.1 | MCU_MISO: R120.2 -> J102.19 and existing R114.1 |
| AFE R24 | MISO_DRV: U1.43, R24.1 | MISO: R24.2 -> J1.5 -> K1 -> AUX J101.5 -> U102.10 |

Keep R114.2 at TARGET_GND and its 42.2k value unchanged. Putting the proposed
R120 upstream of this branch leaves the receiver-side pulldown with J102 when
the series part is absent. Replacing R114 with a low resistor would instead
load the data line toward ground; it is not a damping substitution. Preserve
all other default-control resistors and their existing electrical assumptions.

There must be **no parallel copper/solder-jumper bypass** around a proposed
series position. Its component-absent state is an OPEN connection, not the same
as a fitted 0-ohm link. A documented 0-ohm fit may be used as an *unpowered
continuity/configuration baseline* in the later design; it proves no damping
and is not automatically approved for first power. The actual fit, MPN and
allowed tuning alternatives require their own recorded electrical/process basis.
No numeric nonzero resistor is selected in L4. No resistor is inserted in ground,
power or the separate C4 feed/sense paths.

Prefer direct short driver-to-part routing before a long interconnect or fanout,
with the part accessible after assembly. Do not preserve an under-body meander
merely to reach a convenient distant resistor. If all five sites cannot fit
while retaining required bypass/return/clearance/access conditions, revise the
local placement explicitly; do not weaken those guards or silently add tiny
unserviceable packages. The existing 0603 choice is an implementation preference,
not a claim that final placement has passed.

## 3. Account for the other driven segments without pretending they are fixed

L2 contains **eight active driver stages**, not five: MCU SCLK/MOSI/CS drive
U102 inputs; U102 re-drives those three toward the ADC; U1 drives DOUT to U102;
U102 re-drives MISO to the MCU. The five proposed custom-board sites cover only
the last five of those stages. A resistor after U102 cannot damp a new edge
launched by the MCU before U102, or vice versa.

For the three MCU-driven stages, retain the existing commercial DevKit and
captive fanout contract. Do not add a resistor at AUX J102 and call it source
termination at the MCU. Any source-end inline provision would need a supported
attachment near DevKit J1.18/.17/.16 respectively, with the module's own trace,
lead/return geometry and received waveform included. No such attachment or
numeric value is qualified here. Close these stages with applicable channel
evidence or an explicit bounded pilot/rework disposition before their dependent
release; the five-footprint requirement does not waive them.

DRDY and the slower control/arming paths are outside this five-site SPI edit.
They are not presumed immune because they switch less often. In particular,
AFE U1.47's first DRDY via at (50.5,36.4) is also inside U1's nominal body box;
no later bare-track repair is promised there. Their edge/feedback/partial-rail
requirements stay open under F1/L2 and #45. If they require added provisions,
state that scoped change rather than quietly expanding this list or calling
all digital interfaces qualified. Keep all K1 returns and C1 HOST/TARGET
separation; the B3 high-impedance rail-sense leads are not digital signal jumpers.
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

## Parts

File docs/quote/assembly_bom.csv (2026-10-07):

board | population | references | site_count | fitted_qty_per_set | value | active_mpn | quote_mpn | footprint | side | quote_disposition
AFE | FIT | C1;C2;C3;C4 | 4 | 4 | 4.7n | GRM1885C1H472JA01D | GRM1885C1H472JA01D | Capacitor_SMD:C_0603_1608Metric | F.Cu | RETAIN_IDENTITY_PROCESS_REVIEW_OPEN
AFE | FIT | C5 | 1 | 1 | 1.5n | GRM1885C1H152JA01D | GRM1885C1H152JA01D | Capacitor_SMD:C_0603_1608Metric | F.Cu | RETAIN_IDENTITY_PROCESS_REVIEW_OPEN
AFE | DNP | D1;D2;D3;D4;D5;D6;D7;D8 | 8 | 0 | BAV199,215 | BAV199,215 | BAV199,215 | Package_TO_SOT_SMD:SOT-23 | F.Cu | DO_NOT_FIT
AFE | FIT | J1;J2 | 2 | 2 | HTSW-110-07-T-D | HTSW-110-07-T-D | HTSW-110-07-T-D | Connector_PinHeader_2.54mm:PinHeader_2x10_P2.54mm_Vertical | F.Cu | RETAIN_IDENTITY_PROCESS_REVIEW_OPEN
AFE | FIT | R1;R2;R3;R4;R5;R6;R7;R8 | 8 | 8 | 4.99k | RC0603FR-074K99L | RC0603FR-074K99L | Resistor_SMD:R_0603_1608Metric | F.Cu | RETAIN_IDENTITY_PROCESS_REVIEW_OPEN
AFE | FIT | R9;R10 | 2 | 2 | 1M | RC0603FR-071ML | RC0603FR-071ML | Resistor_SMD:R_0603_1608Metric | F.Cu | RETAIN_IDENTITY_PROCESS_REVIEW_OPEN
AFE | FIT | U1 | 1 | 1 | ADS1299-4PAGR | ADS1299-4PAGR | ADS1299-4PAGR | Package_QFP:TQFP-64_10x10mm_P0.5mm | F.Cu | RETAIN_IDENTITY_PROCESS_REVIEW_OPEN
AFE | FIT | C6 | 1 | 1 | 100u | T491D107K016AT | T491D107K016AT | RevA_Passives:T491D_7343_DensityB | F.Cu | RETAIN_IDENTITY_PROCESS_REVIEW_OPEN
AFE | FIT | C7 | 1 | 1 | 22u | T491B226K016AT | T491B226K016AT | RevA_Passives:T491B_3528_DensityB | F.Cu | RETAIN_IDENTITY_PROCESS_REVIEW_OPEN
AFE | FIT | C8;C9;C10;C11;C12;C13;C14;C15;C16;C17;C18;C19;C20;C21;C22 | 15 | 15 | 1u | GRM188R61E105KA12D | GRM188R61C105KA12D | Capacitor_SMD:C_0603_1608Metric | F.Cu | PROPOSED_REPLACEMENT_NOT_APPLIED
AFE | FIT | C23;C24;C25;C26;C27;C28;C29 | 7 | 7 | 100n | GRM188R71H104KA93D | C0603C104K5RACTU | Capacitor_SMD:C_0603_1608Metric | F.Cu | PROPOSED_REPLACEMENT_NOT_APPLIED
AFE | FIT | C30;C31;C32;C33 | 4 | 4 | 10u | GRM219R61A106KE44D | GRM21BR61C106KE15L | Capacitor_SMD:C_0805_2012Metric | F.Cu | PROPOSED_REPLACEMENT_NOT_APPLIED
AFE | FIT | J3 | 1 | 1 | B6B-XH-A(LF)(SN) | B6B-XH-A(LF)(SN) | B6B-XH-A(LF)(SN) | Connector_JST:JST_XH_B6B-XH-A_1x06_P2.50mm_Vertical | F.Cu | RETAIN_IDENTITY_PROCESS_REVIEW_OPEN
AFE | FIT | R11 | 1 | 1 | 10 | RC0603FR-0710RL | RC0603FR-0710RL | Resistor_SMD:R_0603_1608Metric | F.Cu | RETAIN_IDENTITY_PROCESS_REVIEW_OPEN
AFE | FIT | U2 | 1 | 1 | TPS7A2033PDBVR | TPS7A2033PDBVR | TPS7A2033PDBVR | Package_TO_SOT_SMD:SOT-23-5 | F.Cu | RETAIN_IDENTITY_PROCESS_REVIEW_OPEN
AFE | FIT | R12;R13;R15;R16;R17;R18;R19 | 7 | 7 | 42.2k | RC0603FR-0742K2L | RC0603FR-0742K2L | Resistor_SMD:R_0603_1608Metric | F.Cu | RETAIN_IDENTITY_PROCESS_REVIEW_OPEN
AFE | FIT | R14;R20;R21;R22;R23 | 5 | 5 | 10k | RC0603FR-0710KL | RC0603FR-0710KL | Resistor_SMD:R_0603_1608Metric | F.Cu | RETAIN_IDENTITY_PROCESS_REVIEW_OPEN
AUX | LANDING_ONLY | J101 | 1 | 0 | K1_NUMBERED_SOLDER_TAILS | PCB_LANDINGS_ONLY | PCB_LANDINGS_ONLY | Aux_Lands:SolderTails_20 | F.Cu | COPPER_ONLY_NOT_A_PURCHASE
AUX | LANDING_ONLY | J102 | 1 | 0 | DEVKIT_J1_NUMBERED_TAILS | PCB_LANDINGS_ONLY | PCB_LANDINGS_ONLY | Aux_Lands:SolderTails_22 | F.Cu | COPPER_ONLY_NOT_A_PURCHASE
AUX | LANDING_ONLY | J103 | 1 | 0 | ADAFRUIT_5335_TAILS | PCB_LANDINGS_ONLY | PCB_LANDINGS_ONLY | Aux_Lands:SolderTails_4 | F.Cu | COPPER_ONLY_NOT_A_PURCHASE
AUX | FIT | J104 | 1 | 1 | B6B-XH-A(LF)(SN) | B6B-XH-A(LF)(SN) | B6B-XH-A(LF)(SN) | Connector_JST:JST_XH_B6B-XH-A_1x06_P2.50mm_Vertical | F.Cu | RETAIN_IDENTITY_PROCESS_REVIEW_OPEN
AUX | LANDING_ONLY | J105 | 1 | 0 | REGULATED_5V_TAILS | PCB_LANDINGS_ONLY | PCB_LANDINGS_ONLY | Aux_Lands:SolderTails_2 | F.Cu | COPPER_ONLY_NOT_A_PURCHASE
AUX | LANDING_ONLY | J106 | 1 | 0 | REMOTE_NO_STOP_CONTACT | PCB_LANDINGS_ONLY | PCB_LANDINGS_ONLY | Aux_Lands:SolderTails_2 | F.Cu | COPPER_ONLY_NOT_A_PURCHASE
AUX | FIT | U101 | 1 | 1 | ISO7721DR | ISO7721DR | ISO7721DR | Package_SO:SOIC-8_3.9x4.9mm_P1.27mm | F.Cu | RETAIN_IDENTITY_PROCESS_REVIEW_OPEN
AUX | FIT | U102;U103;U104 | 3 | 3 | TXU0304PWR | TXU0304PWR | TXU0304PWR | Package_SO:TSSOP-14_4.4x5mm_P0.65mm | F.Cu | RETAIN_IDENTITY_PROCESS_REVIEW_OPEN
AUX | FIT | U105;U106 | 2 | 2 | TPS3703A4330DSER | TPS3703A4330DSER | TPS3703A4330DSER | Package_SON:WSON-6_1.5x1.5mm_P0.5mm | F.Cu | RETAIN_IDENTITY_PROCESS_REVIEW_OPEN
AUX | FIT | U107;U108 | 2 | 2 | TPS3703A5500DSER | TPS3703A5500DSER | TPS3703A5500DSER | Package_SON:WSON-6_1.5x1.5mm_P0.5mm | F.Cu | RETAIN_IDENTITY_PROCESS_REVIEW_OPEN
AUX | FIT | U109;U110 | 2 | 2 | SN74LVC1G97DBVR | SN74LVC1G97DBVR | SN74LVC1G97DBVR | Package_TO_SOT_SMD:SOT-23-6 | F.Cu | RETAIN_IDENTITY_PROCESS_REVIEW_OPEN
AUX | FIT | U111 | 1 | 1 | SN74LVC2G74DCUR | SN74LVC2G74DCUR | SN74LVC2G74DCUR | Package_SO:VSSOP-8_2.3x2mm_P0.5mm | F.Cu | RETAIN_IDENTITY_PROCESS_REVIEW_OPEN
AUX | FIT | C101;C102;C103;C104;C105;C106;C107;C108;C109;C110;C111;C112;C113;C114;C115 | 15 | 15 | 100n | C0603C104K5RACTU | C0603C104K5RACTU | Capacitor_SMD:C_0603_1608Metric | F.Cu | RETAIN_IDENTITY_PROCESS_REVIEW_OPEN
AUX | FIT | R101;R103;R105;R107;R110;R111;R112;R113 | 8 | 8 | 10k | RC0603FR-0710KL | RC0603FR-0710KL | Resistor_SMD:R_0603_1608Metric | F.Cu | RETAIN_IDENTITY_PROCESS_REVIEW_OPEN
AUX | FIT | R102;R104;R106;R108;R109;R116 | 6 | 6 | 100k | RC0603FR-07100KL | RC0603FR-07100KL | Resistor_SMD:R_0603_1608Metric | F.Cu | RETAIN_IDENTITY_PROCESS_REVIEW_OPEN
AUX | FIT | R114;R115 | 2 | 2 | 42.2k | RC0603FR-0742K2L | RC0603FR-0742K2L | Resistor_SMD:R_0603_1608Metric | F.Cu | RETAIN_IDENTITY_PROCESS_REVIEW_OPEN

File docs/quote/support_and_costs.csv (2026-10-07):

item_id | category | cost_basis | quantity_basis | item | specification_or_target | double_count_or_scope_note | question_ids | vendor | currency | amount_for_1_set | amount_for_5_sets | inclusions_exclusions
B01 | BOARD | per set | 1 AFE board | Bare AFE PCB | 78 x 58 mm; four layers; nominal1.6mm; Q01 stack/finish proposal | Included components are B03 not here | Q01
B02 | BOARD | per set | 1 auxiliary board | Bare auxiliary PCB | 90 x 75 mm; four layers; nominal1.6mm; separate Q01 stack drawing | Do not combine HOST/TARGET grounds | Q01
B03 | PARTS | per set | 104 fitted board parts | Both populated component kits | Use assembly_bom.csv quote_mpn quantities;61AFE+43AUX | Includes all board headers; excludes MOD1/host/cables;D1-D8 zero | Q02;Q03;Q04
B04 | LABOUR | per lot | quote for1 and5sets | SMT assembly | Both designs; front components; WSON exposed pads/T491 polarity | Separate labour from B03 components | Q03;Q05
B05 | LABOUR | per lot | quote for1 and5sets | Through-hole and board tail work | HTSW/XH post-SMT; solder tails with independent restraint | Clarify overlap with cable labour A07-A11 | Q05;Q06
B06 | SETUP | per lot | itemize two designs or shared panel | Engineering setup and stencils | Panel/tooling/fiducial proposal; stencil/paste/mask review | Charge shared work once; ownership and reuse stated | Q01;Q03
B07 | QA | per lot | quote inspection scope | Unpowered inspection and bare-PCB tests | State AOI/microscopy/X-ray applicability; bare-PCB electrical test parameters | No populated-board energization/programming; parameters need approval | Q05;Q09
B08 | OVERAGE | per lot | vendor to state | MOQ attrition and component spares | Itemize cut tape/reel/minimum buys; surplus ownership | NOT already included in fitted quantities | Q02;Q10
A01 | MODULE | per set | 1 | ESP32-S3-DevKitC-1-N8R8 | Official target; actual board revision to inspect; external5V | MOD1 excluded from AFE board placements; do not count twice | Q02;Q09
A02 | MODULE | per set | 1 | Adafruit CP2102N Friend5335 | HOST-side application UART module; not CP2104/unspecified clone | ISO7721DR is already in B03; no extra generic isolator module | Q02;Q09
A03 | CABLE | per set | 2 | IDSD-10-S-04.00-T-G-ST4 | K1;20conductors each;101.6+/-3.175mm;28AWG;6.35mm nominal tinned ends | One J1 and one J2; retain all contacts and distinct cartridge codes | Q06
A04 | CABLE | per set | 1 complete assembly | C4 service cable | 2xXHP-6;10xSXH-001T-P0.6 non-N;5xAWG24;OD0.9-1.9mm;150+/-5mm between housing faces | Pins1-5 one-to-one; cavity6empty;board headers already in B03 | Q06
A05 | MECHANICAL | per set | 1 complete K2 set | AFE carrier and coded captures | Use current carrier_k2.scad assembly; material/tolerances/process TBD | Include covers bridges saddles bars clips and fastening concept once | Q07
A06 | MECHANICAL | per set | 1 support set | Auxiliary and module supports | 4auxNPTH supports plus independent DevKit/HOST supports and cable restraint | OffsetH4;no conductive HOST/TARGET bridge; exact fasteners TBD | Q07
A07 | HARNESS | per set | 1 fanout assembly | Controller permanent tails | AUX J102 to same-numbered DevKit J1;19used positions;3/13/14unused | Wire lengths/gauge/termination proposed for review; no new connector assumed | Q06;Q09
A08 | HARNESS | per set | 1 four-wire set | HOST permanent tails | AUX J103.1/2/3/4 to HOST JP4.2/JP1.1/JP1.4/JP1.5 respectively | HOST3V3 is not HOST USB5V; domain separation retained | Q06
A09 | HARNESS | per setup | 1 paired lead set | Source leads and interfaces | Target common outgoing+return resistance <=0.050ohm under intended conditions | Planning target not guaranteed resistance;actual source connector TBD | Q06;Q09
A10 | CONTROL | per set | 1 contact and two-lead set | Remote normally-open STOP | AUX J106; exact device and restraint to be proposed | Control contact not a power switch or safety-rated emergency stop | Q06;Q09
A11 | FIXTURE | per setup | 1 fixture set | Passive analog-startup and dummy fixture | Separate proposed design/cost; use AFE J2 allocation; external mode disabled | Not a released fixture or permission to energize inputs | Q09
A12 | CABLE | per setup | 1 | HOST USB data cable | Suitable for Adafruit5335; only HOST connection during eventual reviewed capture | Both DevKit USB ports excluded with accessories | Q09
A13 | MECHANICAL | per lot | itemized consumables | Insulation fasteners shims and strain relief | Accepted nonconductive material/process; actual quantities proposed | Remove items already included in A05/A06/A07-A10 | Q06;Q07
L01 | LAB | shared equipment | 1 source or borrowed | Regulated5V bench supply | Adjustable current limit/output-enable;>=1A available capacity | Capacity is NOT initial limit; not a selected/purchased instrument | Q09
L02 | LAB | shared equipment | as required or borrowed | Meter scope probes and passive test tools | Accuracy grounding and current-injection limits reviewed before use | Separate incremental equipment cost; no assumed free instrument | Q09
L03 | LAB | one-time tooling | vendor included or itemized | Crimp solder fixture tooling | Qualified cable and solder process; no improvised crimp assumption | Avoid charging same tooling in A04/B05/B06 | Q05;Q06
D01 | DELIVERY | per shipment | vendor to state | Packing shipping insurance | ESD-safe pack; combine services only with stated scope | Destination country/postcode not yet selected | Q10
D02 | DELIVERY | per shipment | vendor to state | Tax import and handling | State included/excluded charges and responsibility | Do not assume a rate country currency or zero tax | Q10

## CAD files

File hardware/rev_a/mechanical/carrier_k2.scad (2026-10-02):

// K2 dimensioned FIT PROTOTYPE. Millimeters. No fabrication or safety approval.
// Datum: PCB top z=0; board coordinates retained from the authored KiCad source.
// Use from view_k2.scad or a test harness; this library emits nothing on import.
// OpenSCAD 2021.01; no external libraries or font dependencies.
function ports() = [[81.27,38.43], [16.27,43.43]];
function code_y(port) = assert(port==0 || port==1) (port==0 ? 7 : -7);
function mount_half_pitch(port) = port==0 ? 15 : 18;
function mount_x(port) = port==0 ? 91.5 : 6.5;
function contact_y(side) = side==0 ? [32,48] : [27,43];

module box(lo,hi) { translate(lo) cube(hi-lo); }
module hole_at(x,y,z0,z1,d) {
    translate([x,y,z0]) cylinder(h=z1-z0,d=d,$fn=32);
}

// Local port XY. Open cable side is -X; two return tabs still constrain corners.
// K1's closed ring obstructed the horizontal IDC cable. This is intentionally
// a slotted receiver, not the unmodified rectangular K1 model.
module receiver(port=0, closed_cable_wall=false, rib=true) {
    union() {
        difference() {
            box([-5.2,-15.5,9.5],[5.2,15.5,14.5]);
            box([-4.2,-14.5,9.49],[4.2,14.5,14.51]);
            // 0.2-mm entrance bevel; code rib remains a positive solid stop.
            translate([0,0,14.3]) linear_extrude(height=0.21,scale=[8.8/8.4,29.4/29])
                square([8.4,29],center=true);
            if (!closed_cable_wall)
                box([-5.21,-12.8,9.49],[-4.19,12.8,14.51]);
        }
        if (rib) box([3.4,code_y(port)-1,9.5],[4.21,code_y(port)+1,14.5]);
    }
}

// Socket datum is its mating face. The end ledges are OUTSIDE the male body,
// never a washer between mating faces. Accepted socket dimensions are inspection
// requirements: width <=5.30 (REF is not a maximum), length 26.77..27.28,
// height 9.14..9.52. Real socket/cable inspection and process tolerances are OPEN.
module cartridge(port=0, groove=true) {
    difference() {
        union() {
            box([-4,-14.3,-0.6],[4,14.3,12.8]);
            // Fastening ears are above the guide even after 0.56 axial travel.
            box([-6,-14.3,12.8],[6,14.3,14.3]);
        }
        box([-2.75,-13.7,0],[2.75,13.7,14.31]);
        box([-2.75,-12.9,-0.61],[2.75,12.9,0.01]);
        // Ribbon leaves the SOCKET laterally; preserve it throughout insertion.
        box([-6.01,-12.8,6.1],[-2.74,12.8,10.1]);
        if (groove) box([3.2,code_y(port)-1.2,-0.61],[4.01,code_y(port)+1.2,12.81]);
        for (x=[-4.8,4.8], y=[-11,11]) hole_at(x,y,12.79,14.31,1.5);
    }
}

// Removable only by destroying/replacing four mechanically upset plastic rivets.
// Rivet geometry/material/process not qualified. Continuity and cable exit must
// be inspected BEFORE capture; this is not a self-verifying factory assembly.
module cap() {
    difference() {
        union() {
            box([-6,-14.3,14.3],[6,14.3,15.8]);
            for (y=[-13.0,13.0])
                box([-2.65,y-0.5,9.7],[2.65,y+0.5,14.31]);
        }
        for (x=[-4.8,4.8], y=[-11,11]) hole_at(x,y,14.29,15.81,1.5);
    }
}
module plug(port=0) { cartridge(port); cap(); }

// Nominal / bounding envelopes for fit checks, not detailed connector models.
module header_envelope() {
    box([-2.515,-12.7635,0],[2.515,12.7635,2.54]);
    for (x=[-1.27,1.27], i=[0:9])
        box([x-0.355,-11.43+2.54*i-0.355,2.54],
            [x+0.355,-11.43+2.54*i+0.355,9]);
}
module socket_envelope() { box([-2.65,-13.64,0],[2.65,13.64,9.52]); }
module cable_envelope() { box([-25,-12.7,6.2],[-2.54,12.7,7.8]); }

// M1 contact strips preserved. All other fixture support comes from OUTSIDE PCB.
// Board nominal bottom -1.6; shim support/inspect board datum for actual thickness.
module carrier() {
    union() {
        // C4 support at screened bare underside regions; no PCB holes.
        box([59,11.5,-7.01],[61,18,-1.6]);
        box([76.5,11.5,-7.01],[78.5,18,-1.6]);
        difference() {
            box([-6,4,-10],[96,74,-7]);
            // Fixture fasteners ONLY, never PCB holes.
            for (x=[0,92], y=[7,71]) hole_at(x,y,-10.1,-6.9,3.2);
        }
        for (side=[0,1]) {
            rail_x = side==0 ? 2 : 88.5;
            difference() {
                union() {
                    // Low rail/retainers leave the lateral J2 ribbon unobstructed.
                    box([rail_x,20,-7.01],[rail_x+7.5,64,4]);
                    port=1-side; p=ports()[port];
                    for(sy=[-1,1])
                        box([mount_x(port)-3.25,p[1]+sy*mount_half_pitch(port)-3.25,3.99],
                            [mount_x(port)+3.25,p[1]+sy*mount_half_pitch(port)+3.25,9.5]);
                }
                for (y=contact_y(side)) hole_at(side==0 ? 6.5 : 91.5,y+3,-1.5,4.01,2.0);
                port=1-side; p=ports()[port];
                for(sy=[-1,1]) hole_at(mount_x(port),p[1]+sy*mount_half_pitch(port),-1.5,9.51,2.0);
            }
            for (y=contact_y(side)) {
                x0=side==0 ? 2 : 86.5;
                x1=side==0 ? 11.5 : 96;
                box([x0,y,-7.01],[x1,y+6,-1.6]);
            }
        }
    }
}

// Detachable raised guide bridges: remove them before installing/removing PCB.
// Different 30/36-mm screw spacings prevent a two-fastener wrong-side installation.
module bridge(port=0) {
    p=ports()[port]; mx=mount_x(port)-p[0]; half=mount_half_pitch(port);
    // Build all touching faces in one local datum, then translate the solid.
    // Mixing translated local geometry with independently rounded global boxes
    // introduced sub-resolution slivers and collinear triangles in ASCII STL.
    translate([p[0],p[1],0]) difference() {
        union() {
            receiver(port);
            for(sy=[-1,1]) {
                yy=sy*15;
                box([min(-20,mx),yy-0.5,9.5],[max(5.2,mx),yy+0.5,12]);
                box([mx-3.25,sy*half-3.25,9.5],
                    [mx+3.25,sy*half+3.25,12]);
            }
            translate([-16,0,0]) saddle();
        }
        for(sy=[-1,1]) hole_at(mx,sy*half,9.4,12.1,2.8);
    }
}
module frame() { carrier(); bridge(0); bridge(1); }

module saddle() {
    difference() {
        union() {
            box([-4,-16,7.0],[4,16,8.5]);
            for(y=[-14.8,14.8]) box([-4,y-1.2,8.49],[4,y+1.2,10.7]);
        }
        for(y=[-14.8,14.8]) hole_at(0,y,6.9,10.8,2.2);
    }
}
module strain_bar() {
    difference() {
        box([-4,-16,10.7],[4,16,12.2]);
        for(y=[-14.8,14.8]) hole_at(0,y,10.6,12.3,2.2);
    }
}

// Four separately installed cantilever hold-downs. Mirror for right edge.
// 0.10-mm nominal top gap: actual shim/retention adjustment required, not a clamp
// force specification. The column/fastener must not bottom against the board.
module edge_clip() {
    difference() {
        union() {
            box([3.5,0,4],[10.8,6,5.5]);
            box([10,0,0.10],[10.8,6,4.01]);
        }
        hole_at(6.5,3,3.9,5.6,2.2);
    }
}

// Blanket z=0..4 component allocation, EXCEPT the K1 cartridge column and M1
// contact strips. This is conservative but not detailed manufactured part CAD.
// C4 conservative body/mate allocation; no physical fit guarantee.
module service_envelope() { box([59.5,11,0],[78,19,12]); }

module board_and_component_allocation() {
    service_envelope();
    // Exclude only the 1-um skin of intentional bottom support contact; CGAL
    // otherwise retains zero-volume faces in STL intersections. Not fit tolerance.
    box([10,10,-1.599],[88,68,0]);
    difference() {
        box([10,10,0],[88,68,4]);
        for(p=ports()) translate([p[0],p[1],0]) box([-4,-14.3,-.01],[4,14.3,4.01]);
        for(side=[0,1], y=contact_y(side))
            box([side==0 ? 10 : 86.5,y,-.01],[side==0 ? 11.5 : 88,y+6,4.01]);
    }
}

module assembly(explode=0) {
    color([0.65,0.7,0.75]) carrier();
    translate([0,0,explode*0.5]) color([0.6,0.65,0.7]) { bridge(0); bridge(1); }
    color([0.15,0.4,0.25]) box([10,10,-1.6],[88,68,0]);
    for (port=[0,1]) {
        p=ports()[port];
        translate([p[0],p[1],0]) {
            color([0.25,0.25,0.25]) header_envelope();
            translate([0,0,2.54+explode]) {
                color([0.25,0.6,0.8]) cartridge(port);
                color([0.2,0.2,0.2]) socket_envelope();
                color([0.7,0.7,0.7]) cable_envelope();
                translate([0,0,explode]) color([0.3,0.6,0.8]) cap();
            }
        }
        translate([p[0]-16,p[1],explode]) color([0.6,0.6,0.6]) strain_bar();
    }
    for(side=[0,1], y=contact_y(side))
        translate([side==0 ? 0 : 98,y,explode])
            scale([side==0 ? 1 : -1,1,1]) color([0.7,0.7,0.7]) edge_clip();
}

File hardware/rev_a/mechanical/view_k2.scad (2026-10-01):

// Open this file in OpenSCAD. F6 is a solid render, not mechanical qualification.
use <carrier_k2.scad>
part = "assembly"; // [assembly,exploded,carrier,bridge_J1,bridge_J2,cartridge_J1,cartridge_J2,cap,edge_clip,strain_bar]
if (part=="assembly") assembly();
else if (part=="exploded") assembly(10);
else if (part=="carrier") carrier();
else if (part=="bridge_J1") bridge(0);
else if (part=="bridge_J2") bridge(1);
else if (part=="cartridge_J1") cartridge(0);
else if (part=="cartridge_J2") cartridge(1);
else if (part=="cap") cap();
else if (part=="edge_clip") edge_clip();
else if (part=="strain_bar") strain_bar();
else assert(false,"unknown K2 part");

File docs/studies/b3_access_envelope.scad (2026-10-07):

// B3 read-only access study, NOT printable hardware or a released harness.
// Millimetres; existing K2 datum: PCB top z=0. OpenSCAD 2021.01.
// Inspect nominal free-space corridors, not joint/force/electrical qualification.
use <../../hardware/rev_a/mechanical/carrier_k2.scad>
mode = "view"; // view, routes, vertical_c6, vertical_c30, vertical_c31,
               // vertical_c32, vertical_c33, blocked_routes, blocked_raised

module retained_obstacles() {
    frame(); service_envelope();
    for (port=[0,1]) {
        p=ports()[port];
        translate([p[0],p[1],0]) {
            header_envelope();
            translate([0,0,2.54]) { plug(port); socket_envelope(); cable_envelope(); }
        }
        translate([p[0]-16,p[1],0]) strain_bar();
    }
    for(side=[0,1], y=contact_y(side))
        translate([side==0 ? 0 : 98,y,0])
            scale([side==0 ? 1 : -1,1,1]) edge_clip();
}
module segment(a,b,r) { hull() {
    translate(a) sphere(r=r,$fn=16);
    translate(b) sphere(r=r,$fn=16);
} }
module route(points,r) { for(i=[0:len(points)-2]) segment(points[i],points[i+1],r); }

// Each line is a PAIR corridor (two separately insulated wires), not copper.
// r=0.50 includes assumed bundle radius plus its allowed displacement.
// Local solder exits below z=5.5 are intentionally NOT validated by this model.
module pair_corridors(z=5.5) {
    route([[52.2,48.4,z],[54.5,48.4,z],[54.5,77,z]],0.5); // C6 positive exit
    route([[52.2,56.6,z],[54.5,56.6,z]],0.5); // C6 return joins insulated pair
    route([[63.0,29.5,z],[66,29.5,z],[66,31,z],[56.5,31,z],
           [56.5,28,z],[54.5,28,z],[54.5,1,z]],0.5); // C30
    route([[50.7,20,z],[53.3,20,z],[51,17,z],[51,1,z]],0.5); // C31
    route([[43,23.2,z],[45.6,23.2,z],[45,19,z],[45,1,z]],0.5); // C32
    route([[73.7,23,z],[76.3,23,z],[76.3,21,z],[57,21,z],[57,1,z]],0.5); // C33
}
module vertical_pair(ref) {
    pts = ref==6 ? [[52.2,48.45],[52.2,56.55]] :
          ref==30 ? [[63,29.5],[65.6,29.5]] :
          ref==31 ? [[50.7,20],[53.3,20]] :
          ref==32 ? [[43,23.2],[45.6,23.2]] : [[73.7,23],[76.3,23]];
    for(p=pts) translate([p[0],p[1],4.1]) cylinder(h=25.9,d=0.5,$fn=32);
}
// Disjoint 1 mm^3 witness makes an empty intersection a valid mesh.
module collision(route_mode=false,z=5.5,ref=6) {
    union() {
        translate([120,120,120]) cube(1);
        intersection() {
            if(route_mode) pair_corridors(z); else vertical_pair(ref);
            retained_obstacles();
        }
    }
}
if(mode=="view") {
    color([0.75,0.75,0.75,0.6]) retained_obstacles();
    color([0.25,0.5,0.3,0.3]) translate([10,10,-1.6]) cube([78,58,1.6]);
    color([0.9,0.4,0.1]) pair_corridors();
} else if(mode=="routes") pair_corridors();
else if(mode=="blocked_routes") collision(true);
else if(mode=="blocked_raised") collision(true,8.0);
else if(mode=="vertical_c6") collision(false,5.5,6);
else if(mode=="vertical_c30") collision(false,5.5,30);
else if(mode=="vertical_c31") collision(false,5.5,31);
else if(mode=="vertical_c32") collision(false,5.5,32);
else if(mode=="vertical_c33") collision(false,5.5,33);
else assert(false,"unknown inspection mode");

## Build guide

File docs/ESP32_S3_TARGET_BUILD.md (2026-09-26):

# Explicit ESP32-S3 compile target — not bench validation

This is an opt-in target build for the selected Rev A four-channel arrangement.
It does not release the schematic, validate wiring or permit hardware operation.
`BOARD_PROFILE_REVIEWED` stays **false** and the sketch halts before configuring
ADS control GPIOs. Internal test/short mux paths are the only acquisition modes;
BIAS, lead-off, SRB1 and Wi-Fi defaults remain disabled as before. No upload or
flashing command is part of the workflow.

## Profile contract

The new `board_config_rev_a_s3.h` contains the proposed GPIOs from the existing
validated hardware JSON: SCLK 12, MISO 13, MOSI 11, CS 10, DRDY 4, RESET 5,
START 6, PWDN 7 and controlled CLKSEL 8. Tests compare every pin with the hardware source of truth.
The header also requires the selected four-channel ADS1299 variant at runtime.
That check is reachable only after the separate wiring-review gate is approved;
this change does not approve it.

Selection requires the explicit compiler definition `EEGLAB_REV_A_S3`. Merely
choosing an S3 MCU does not silently select a wiring profile. The original
ESP32 default pin map and its target restriction are retained in `board_config.h`.
The S3 header rejects any target other than `CONFIG_IDF_TARGET_ESP32S3`.
Native compiler fixtures exercise accepted and rejected combinations. They are
header/guard tests, not a substitute for the real Xtensa/Arduino target build.

The baseline JSON's original `existing_firmware_modified: false` records the
scope of the historical hardware-baseline commit. This later, explicitly scoped
firmware PR supplies the planned S3 profile without changing that baseline or
setting `firmware_port_validated`, `board_profile_reviewed`, or any other gate.

## Controlled startup candidate

The later startup correction adds `rev_a_startup.h`, invoked only by the
explicit S3 path and only after the unchanged review guard. Read
[`REV_A_STARTUP_SEQUENCE.md`](REV_A_STARTUP_SEQUENCE.md): two fresh operator
acknowledgments separate stable-rail/passive-fixture setup and measured VCAP1
from clock enable/reset. These are not sensed voltages or physical validation.
The legacy ESP32 path retains its prior startup behavior.

## Reproducible toolchain

`firmware/toolchain.json` is the version/FQBN source for CI and `tools.check`.
The build uses Arduino CLI **1.3.1**, pinned to the official Linux amd64 package
SHA-256, and Arduino-ESP32 **3.3.12**, not a moving latest or release candidate.
The requested target has 8 MB flash and OPI PSRAM enabled in the build options;
the capture buffer still uses internal RAM. This is a compiler configuration,
not evidence that a particular physical module or PCB revision was inspected.

Primary provenance:
- https://github.com/arduino/arduino-cli/releases/tag/v1.3.1
- https://github.com/espressif/arduino-esp32/releases/tag/3.3.12
- https://espressif.github.io/arduino-esp32/package_esp32_index.json

The official core installer verifies its package checksums. The exact installed
CLI version, core list and board properties are retained with the build log.
The CLI binary is hash-checked before execution; project dependencies remain
managed by the unchanged Python lockfile.

After installing the versions in that file:

```bash
uv sync --locked --all-extras
uv run --locked python -m tools.check --firmware
```

The new `Firmware` workflow installs that toolchain and runs the same command.
The ordinary software and native/simulation jobs remain separate. Firmware mode
fails when the compiler or required versions are absent. Each target compile
uses a fresh output directory; a zero exit without new binary artifacts fails.
The CI checkout explicitly selects the PR head (or the push commit); it does not
call a synthetic merge checkout exact-head evidence.
`FIRMWARE_BUILD.json` records the source commit, source-file hashes, toolchain,
directory and binary SHA-256s with
all physical/review/body-use flags false. It is written only after success.
A new firmware request invalidates the old marker before even the ordinary
quality checks; an earlier failure cannot leave an old build looking current.

## Evidence and limits

The test-only commit precedes implementation and preserves the missing-profile
and missing-command failures. Consult the PR's **exact-head** `ESP32-S3 target
compile` job and retained artifact for whole-sketch evidence. No document alone
establishes that a new source revision compiled. The current environment cannot
cross-compile offline until the pinned Arduino toolchain is installed; the actual
cross-compile runs in the dedicated CI job.

Target compilation does not validate SPI timing, ISR latency, serial throughput,
reference/power wiring, regulator behavior, signal quality or body-interface
safety. A physical port remains unvalidated. The next step remains schematic/
pin review and person-disconnected bench testing, not connecting electrodes.

## Physical header console continuation

The S3 FQBN now pins `CDCOnBoot=default`. The false review-stop path retains
the existing onboard UART0 diagnostic; the reviewed path explicitly remaps the
application UART to RX17/TX18, 460800 8N1, on DevKit J1 pads10/11. An enabled
USB CDC build is rejected. This avoids sharing the onboard bridge's output or
combining normal USB power with the external bench rail. See
`REV_A_BENCH_HARNESS.md` for the separate programming/acquisition arrangements,
interface qualification still required and physical-evidence limits. Host call
traces and target compilation are not actual adapter/baud validation.

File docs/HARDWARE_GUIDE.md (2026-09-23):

# Hardware guide: buy the right thing, then test it in layers

**Current status (Rev A): the component baseline is selected, but no physical circuit has been tested.** See [HARDWARE_BASELINE_REV_A.md](HARDWARE_BASELINE_REV_A.md) and `hardware/rev_a/` for the exact ADS1299-4 + ESP32-S3 devkit decision, BOM, proposed pin map, provenance, and fail-closed review gates. The generic/original-ESP32 material below remains useful background; where it conflicts with Rev A, the Rev A baseline is authoritative for new simulation and schematic work. This document separates a concrete digital bench example from the connections that cannot yet be specified responsibly.

The included firmware is deliberately restricted to the ADS1299's **internal test signal or internally shorted inputs**. There is no external-electrode acquisition mode to enable. An acquisition waveform is not evidence of electrical safety.

## 1. The $100 decision

Do not buy a bare ADS1299 chip just because the software mentions it. A chip, a breakout adapter, an evaluation board, and a protected assembled recorder are four different purchases.

At the research check, DigiKey listed the full eight-channel ADS1299IPAGR at **$88.58 for one bare chip**, with zero immediate stock on that listing. Its related four-channel ADS1299-4PAGR listing showed **$44.99**. Prices, availability, taxes and shipping are not fixed [S9, S10]. Neither price includes a usable front-end PCB, input protection, regulators, assembly, connectors, enclosure or battery.

**A documented assembled ADS1299 system delivered for under $100 has not been verified here.** The earlier reports' custom-PCBA numbers were engineering estimates, not complete purchasing quotations. A one-off manufacturing order also has minimum quantities, shipping and the possibility of a revision.

A useful spending rule is to reserve roughly $35–40 of your ceiling for power, connectors, enclosure, consumables, delivery and contingencies. That leaves roughly $60–65 for an assembled front-end board. These are **budget allocations, not market prices**. A missing multimeter, unsuitable electrode connectors, or additional shipping reduces that board ceiling further. Obtain a complete quote before spending.

Your existing ESP32 and electrodes may avoid some purchases, but their exact models and connector/material details still need checking. Do not assume they are Ag/AgCl electrodes merely because the older report discussed that type.

For now: run the lab, identify the boards, and keep the $100 unspent. A four-channel ADS1299-4 board is a reasonable candidate to investigate; a cheap anonymous listing is not automatically a good choice. More physical channels do not fix poor documentation, noisy inputs or an unsafe power arrangement.

## 2. Before paying: the board worksheet

Save the listing, schematic and board revision. Fill in `configs/board_profile.example.json`. This is a human review worksheet; it is not automatically consumed by the firmware.

| Required information | Why it matters |
|---|---|
| Manufacturer, model, revision and clear photographs | Similar-looking boards can expose different supplies and connectors. |
| Exact ADC variant: 4, 6 or 8 channels | Determines native frame length and available channels. |
| Full schematic, not just a sales diagram | Needed to check supplies, reference, clock, input paths and bias. |
| Board supply input and every regulator/rail | A connector marked “5V” may be a regulator input, not a chip pin. |
| Digital interface voltage | Our bench example requires compatible 3.3-V logic. |
| Clock source and CLKSEL arrangement | The sketch assumes the internal oscillator is selected. |
| Internal-reference support and capacitors | Register settings alone cannot install missing components. |
| CS, DRDY, RESET, START and PWDN straps/headers | Do not drive a signal that is hard-strapped incompatibly. |
| Input protection, reference routing and bias circuit | These are board-specific and cannot be inferred from “ADS1299.” |
| Compatible electrode connectors and enclosure | Loose temporary jumpers are not a finished wearable interface. |

A seller saying “EEG” or “medical chip” does not settle those questions. TI explicitly describes its own evaluation platform as laboratory engineering equipment, not a direct patient interface [S2].

## 3. Power: the connection deliberately left blank

The ADS1299's recommended analog supply span is 4.75–5.25 V; its digital supply is a different domain. The chip supports 1.8–3.6 V digital supplies, and the present ESP32 wiring example requires **3.3-V-compatible digital signaling** [S1, S4].

**Do not simply connect ESP32 3V3 to ADS1299 AVDD. Do not simply connect 5 V to a pin labeled DVDD. Do not infer the board's power input from a chip-level diagram.**

Examples of chip analog rails include a 0/5-V arrangement or a bipolar arrangement with approximately a 5-V span. This statement is not a prescription for your board. Its regulators, reference, input common mode and digital return must be checked together.

No battery or power-pin wiring is provided until that board is known. Use an appropriate documented power source and enclosure for the selected board; do not improvise a loose lithium-cell charging arrangement. All power measurements in the initial stage are made **with no person connected**.

## 4. Conditional digital bench wiring

**This table is for an original ESP32/WROOM-32-style board, not ESP32-C3, S2, S3, C6 or an arbitrary development board. Numbers are GPIO identifiers, not physical header positions.** The SPI signal choices follow the original ESP32 example; the other GPIO assignments are choices made for this project [S4].

The ADS board must expose these signals and use compatible 3.3-V digital levels. Inspect its schematic before moving any wire. Disconnect power while changing wiring.

| Original ESP32 GPIO | Direction | ADS1299-board signal | Meaning |
|---|---|---|---|
| 18 | ESP32 → ADC | SCLK | Serial clock |
| 23 | ESP32 → ADC | DIN / MOSI | Commands and register writes |
| 19 | ADC → ESP32 | DOUT / MISO | Register values and conversion data |
| 27 | ESP32 → ADC | /CS | Select this ADC for an SPI transaction |
| 26 | ADC → ESP32 | /DRDY | A new simultaneous sample frame is ready |
| 25 | ESP32 → ADC | /RESET | Reset control, if exposed and not conflicting with straps |
| 32 | ESP32 → ADC | START | Held low; this sketch uses START/STOP commands |
| 33 | ESP32 → ADC | /PWDN | Power-down control, if exposed and not conflicting with straps |
| Circuit digital return | Shared | DGND / documented digital return | Logic reference within the bench circuit, **not household earth** |

Power and electrode connections are intentionally **not rows in this pin map**. A GPIO table does not define the complete circuit.

Do not put the Uno's 5-V outputs onto this 3.3-V interface. This project does not include a reviewed level-shifter design for the Uno. Use your breadboards for basic passive lessons and low-risk digital bench interconnects; do not make a solderless-breadboard front end your body-connected endpoint.

## 5. Firmware: what it does and does not promise

The folder `firmware/esp32_ads1299_bench` is an Arduino sketch. `portable_core.h` was compiled and tested with native C++ against the Python packet encoder. **The entire sketch was not compiled for ESP32 or run on an ESP32 in this environment.** Native compilation does not validate Arduino API compatibility, GPIO behavior, interrupt timing, power, SPI or Wi-Fi performance.

The sketch initially refuses to configure ADS control pins because `BOARD_PROFILE_REVIEWED` is false. After the bench schematic/power review, the remaining intended sequence is: compile for the exact supported ESP32, upload with no body electrodes connected, then inspect the serial startup diagnostics.

The sketch reads the ADC ID, determines the physical channel count, sets and checks registers, selects internal test or internal short, waits for reference settling, and acquires at a nominal 250 samples/s and gain 24. It uses SPI mode 1 at 1 MHz. An invalid frame prefix, failed register readback, or data timeout halts and asserts power-down. Read the actual source rather than copying isolated register numbers [S1].

`USE_INTERNAL_TEST = true` selects the approximately 0.9766-Hz internal test waveform at the nominal 2.048-MHz clock. `false` selects internally shorted inputs. **Neither setting is an external EEG mode.** Bias derivation, bias drive and lead-off excitation remain disabled.

`USE_WIFI_UDP = false` sends a custom binary USB serial stream for bench use. It is not Arduino Serial Plotter CSV. Optional Python support requires:

```bash
uv run --locked python -m pip install -r requirements-serial.txt
uv run --locked python run_lab.py serial --port /dev/ttyUSB0 --seconds 30 \
  --out results/internal_test.bin --acknowledge-bench-only
uv run --locked python run_lab.py decode results/internal_test.bin --out results/internal_test.csv
uv run --locked python run_lab.py inspect results/internal_test.csv --out results/internal_test_quality
```

The serial device name is an example; Windows often uses a `COM` name. Every body lead, including reference and bias, must be disconnected throughout USB bench capture. That acknowledgement flag is not an isolation mechanism.

The optional UDP path is still bench-only in this firmware. Set the private Wi-Fi credentials and computer address explicitly. Do not assume radio performance is validated simply because localhost passed. Wi-Fi may introduce interference or scheduling delays; the counter checks help reveal acquisition losses but cannot prove analog quality.

## 6. Bench gates, in order

| Gate | Test with no person connected | Proceed only when |
|---|---|---|
| A: Documentation | Inspect board identity, schematic and assembly | Power, reference, clock, input paths and interface levels are understood. |
| B: Power | Check for shorts with power off; measure documented rails/reference after powering | Measurements match the selected board's documentation; nothing overheats. |
| C: Digital identity | Read ID and configuration registers | ID/channel count and register readback are repeatable, not random or all-zero/all-one. |
| D: Internal waveform | Capture the on-chip test signal | Frequency, sign, channel framing, code scale and counters are plausible and repeatable. |
| E: Internal short | Capture a longer baseline in internal-short mode | There is a stable quantified noise spectrum and no unexplained railing or packet loss. |
| F: External dummy network | After a separate external-input firmware/design review, use resistors and known test signals, never a person | Known amplitudes, offsets, input/common-mode limits and interference behavior have been measured. |
| G: Body-interface review | Review physical input protection, bias stability/current limiting, enclosure, power and all possible connections | A competent reviewer or appropriately documented finished system supports the intended body-connected arrangement. |

The current deliverable can support the software and internal bench stages. It does not supply a reviewed implementation for gates F or G. Merely enabling normal-input mux codes would not complete them.

For a future external calibration, amplitude must be small enough **and centered at a valid analog common mode**. Grounding both inputs to 0 V on a unipolar 0/5-V design is not automatically a valid low-noise input condition. This is why the first short test uses the chip's internal mux rather than an invented external jumper.

A grounded function generator or oscilloscope can be used for bench-only dummy tests, but it must never remain electrically connected when a person is connected. Do not place mains voltage on the dummy network to “simulate interference.” Use a properly limited bench test source after reviewing the circuit.

No fixed “noise below X means safe/good” threshold is prescribed here. Noise depends on gain, rate, bandwidth, source impedance, reference, layout and implementation. A quiet internal-short recording does not characterize the complete electrode-connected system.

## 7. The body-connection boundary

For eventual body-connected recording, the acquisition side must have a reviewed body interface, appropriate battery operation, and wireless-only communication in this project plan. OpenBCI's documented battery-only Cyton is a useful architectural precedent, not certification of a different homemade board [S11].

**While any electrode is attached: no USB cable, charger, oscilloscope, function generator, wired debugger, grounded accessory, or other unreviewed conductive connection.** A battery-powered laptop connected by USB is not a substitute for a properly assessed body interface. A cheap USB isolator is not automatically a medically suitable barrier.

Battery and wireless operation remove some hazardous paths; they do not check every component fault, current path, bias-loop instability or construction defect. None of the numerical tests here assesses those hazards. Do not connect the current breadboard or unreviewed module to your body.

Use recording-only experiments. Do not repurpose the bias circuit or electrode wiring for stimulation. Avoid broken or irritated skin and stop on discomfort. This is a learning/research project, not diagnosis or treatment.

## 8. What comes next

Rev A removes the need to keep shopping among MCU/AFE architectures. The immediate engineering task is to implement the selected 4.99 kΩ / 4.7 nF differential input network in ngspice, preserve the existing educational circuit as a regression fixture, and sweep source/electrode impedance imbalance, component tolerance, cable capacitance, 50/60-Hz common mode, and bounded clamp leakage.

After that: BIAS/power modeling, a reviewed KiCad schematic, and an explicit ESP32-S3 firmware profile. Purchasing remains blocked until the schematic is reviewed and a complete delivered parts/fabrication/assembly quote is obtained. External-input and body-connected work remain separate later gates.

References marked `[S#]` are linked in [SOURCES.md](SOURCES.md); Rev A source provenance is in `hardware/rev_a/sources.json`.

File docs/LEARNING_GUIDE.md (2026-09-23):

# Learning guide: from a fake signal to an understandable EEG system

You do not need to understand the entire circuit before beginning. Start by changing one number, predicting the result, running the program, and comparing your prediction with the output. That loop is the central skill this project is designed to teach.

**The starting experiment costs nothing:** run the synthetic demo and inspect its figures. Hardware is a later, separately reviewed step.

## 1. What we are trying to measure

A recording channel measures a **voltage difference**, not an absolute amount of “brain activity.” In a simplified description:

```text
channel value = voltage at its positive input − voltage at its negative input
```

The computer eventually receives numbers representing that difference. The measured voltage can contain neural activity, eye movements, muscle activity, contact changes, and interference. The fact that a trace changes when you blink does not establish that the trace is predominantly EEG. MNE's artifact guide explains these different contributors [S7].

For practice, imagine a 10-Hz wave with a 10-microvolt peak. “10 Hz” means ten cycles per second. “10 microvolts” means 0.000010 volts. Its peak-to-peak amplitude is 20 microvolts; its RMS amplitude is approximately 7.07 microvolts. Those are three different measurements of the same sine wave. The tests verify its integrated spectral power rather than comparing incompatible amplitude conventions.

Our program **constructs** brain-like waves. It does not simulate neurons, consciousness, a particular person's brain, or a validated head volume conductor. The condition labels describe how the generator changes its output.

## 2. What each physical part would do

| Part | Role in the eventual system | What it does not do |
|---|---|---|
| Electrode and conductive contact | Couple a scalp potential into an input | They do not selectively extract neural activity. |
| Analog front end | Accept small differential signals while handling common mode, input loading, protection and noise | A small IC does not by itself make a safe complete instrument. |
| ADS1299 | Integrates amplifiers, simultaneous ADC channels, reference/clock options and biopotential functions | It does not replace the supporting PCB, power design or safety review. |
| ESP32 | Reads already-digitized values over SPI and forwards packets | Its built-in ADC is not used in this architecture. |
| Computer | Stores raw samples, checks integrity, computes spectra and runs experiments | It cannot recover information that was clipped before digitization. |
| Battery, enclosure and approved input circuitry | Form part of the physical recording system | A battery alone is not a safety certification. |

The ADS1299 device family is documented in TI's datasheet [S1]. With this architecture you do **not** add an ADS1115 after the ADS1299 or feed its output into the Uno's analog input. The ADS1299 output used here is digital.

Keep the Uno for ordinary breadboard lessons and signal-generation experiments **with no person connected**. An extra controller is not needed just because you already own it.

## 3. Three things called “reference” that are easy to mix up

**Electrode reference** is the other potential against which a recording channel is compared. In a common-reference arrangement, several channels share it.

**ADC voltage reference** is the chip's electrical ruler for converting a measured voltage into a digital number. It is not an electrode. The nominal internal reference used by this project is 4.5 V.

**Bias electrode** belongs to a circuit that influences the body's common-mode potential. It is not a second name for the signal reference. A driven-bias output is active circuitry and needs an appropriate current-limited, stable, reviewed implementation [S1, S2].

**Circuit ground** and **household protective earth** are also different concepts. Never connect an electrode, a bias lead, or a cable shield to household earth as a noise remedy.

This package deliberately does not show a jumper from a bare BIASOUT pin to a person. The internal-test firmware leaves the bias driver and lead-off excitation off. Real reference/bias routing depends on the actual board schematic.

## 4. Gain, ADC counts, and why offsets matter

Gain scales the differential voltage before conversion. For a nominal 4.5-V reference and gain 24, our ideal ADS1299 code model has:

```text
input full scale: ±(4.5 / 24) V = approximately ±187.5 mV
one code step: 4.5 / (24 × 2^23) V = approximately 0.02235 µV
```

These are calculated using the datasheet's scaling relationship [S1]. The 24-bit number is signed: negative voltage differences produce negative codes. Zero is a difference near zero, not a statement that no activity exists.

**One code step is not the same as noise-free resolution.** A thermometer can print six decimal places without measuring temperature to six decimal places. The same distinction applies to ADC bits and the noise of the complete electrode/circuit system.

The electrode interface may also introduce a differential DC offset. Suppose a small wave rides on 30 mV of offset. The raw input is not just a few microvolts: it is roughly 30 mV plus that small variation. At the example gain and common mode this can remain within range. At 300 mV, the same gain exceeds the nominal differential range.

A digital high-pass filter can remove an offset from **valid recorded samples**. It cannot undo saturation. Once the amplifier or converter clips, many different real inputs become the same output code. Filtering those codes produces a nicer-looking trace, not the missing measurement.

### Exercise: deliberately break the range

Copy `configs/demo.json` to a new file. Change `differential_offset_mV` to `300`, then run with that `--config`. The analysis should reject the affected data, not announce a successful EEG experiment. Restore the offset afterward.

Changing gain from 24 to 12 increases the nominal differential range. It also changes the input-referred code size and the operating/noise tradeoffs. Do not treat “maximum gain” as a universally optimal setting. The prototype firmware remains fixed at gain 24 for its internal bench tests; changing simulation settings does not change that firmware.

### The second range condition: common mode

Let the two inputs be `Vp` and `Vn`:

```text
differential voltage = Vp − Vn
common-mode voltage = (Vp + Vn) / 2
```

A tiny difference does not guarantee that both input voltages are at acceptable levels. The datasheet specifies additional amplifier headroom constraints. The model checks the datasheet's PGA common-mode relationship as well as differential full scale [S1]. Open `START_HERE.html` and vary gain, offset, and common mode to see the distinction.

That calculator assumes 0-V/5-V analog rails solely to illustrate the equation. It is not instructions for powering an unknown board, and passing its arithmetic is not a protection or safety test.

## 5. What a resistor and capacitor do in our circuit model

A resistor relates voltage and current. A capacitor's impedance depends on frequency. Used together, they can pass slow variations differently from fast ones.

An electrode/contact is much more complicated than one resistor, but an illustrative resistor in parallel with a capacitor is useful for learning. Our two input paths each contain that contact model, a series resistor, a large input resistance, and a small capacitance to the local midpoint. Another capacitor connects the two inputs.

The **local midpoint** in the AC model is the zero of the small-signal calculation. It is not a wire you attach to the building's earth.

The component values in this package are educational parameters. They are **not approved patient-protection values**. Increasing a series resistor can change loading, noise and filtering; it does not constitute a complete fault-current assessment. The model excludes resistor thermal noise, input clamp leakage, board contamination, and many real parasitics.

### Why matched inputs matter

Imagine the same unwanted 50-Hz voltage appearing on both electrodes. Perfectly identical linear input paths produce equal voltages at the amplifier inputs; subtraction removes the equal part. Make the paths unequal, and some of that common-mode voltage becomes a difference before the amplifier sees it.

In the provided illustrative circuit, changing one contact resistance from 10 kΩ to 50 kΩ produces about **63.84 µV differential amplitude for 100 mV common-mode amplitude at 50 Hz**. That is a model result, not a prediction for your future board. Its perfectly balanced case has essentially zero conversion because the equations are symmetric—not because a real circuit has infinite rejection.

### Exercise: change one contact

In a Python session opened in the project folder:

```python
from dataclasses import replace
from lab.analog import InputNetwork, transfer

balanced = InputNetwork()
unbalanced = replace(balanced, r_electrode_n=50_000)
for name, circuit in [("balanced", balanced), ("unbalanced", unbalanced)]:
    leakage = abs(transfer([50], circuit, drive="common")[0])
    print(name, "differential µV for 100 mV common mode:", leakage * 100_000)
```

Repeat with a different contact capacitance. Write down your prediction before running. A software 50-Hz notch might hide one symptom; it does not repair the electrode mismatch.

## 6. What SPICE is, and what actually ran here

A **schematic** is a drawing of electrical connections. A **netlist** is a textual list of connections and components. A **simulator** solves mathematical models of those components. A **PCB layout** describes the physical board. These are related, but they are not interchangeable.

ngspice is a circuit simulator that can consume textual circuit descriptions [S3]. KiCad is useful for design documents and PCB work; a visual circuit on screen still needs correct models, supplies, connectivity and assumptions before its simulation means anything.

This project intentionally has two paths:

```text
Our passive component parameters → Python nodal equations → AC response
Our passive component parameters → ordinary .cir files → ngspice → AC response
```

Only the first path executed in the provided environment. The second is exported and wired into a strict comparison command, but ngspice itself was unavailable. This is not disguised as a skipped “success.”

The Python solver forms a two-by-two complex admittance matrix and solves Kirchhoff's current-law equations. You can inspect it in a small source file. Tests compare limiting cases with independent closed-form results and check symmetry. When ngspice is installed, the program compares both complex responses at the same frequencies.

There is no active body-bias amplifier model, power-supply model, protection circuit, ESD model, or complete ADS1299 silicon macro-model. Those omissions matter when moving toward physical construction.

### Exercise: see the literal circuit description

Run `python run_lab.py circuits`, then open `results/circuits/balanced.cir` in a text editor. Find `Rep`, `Cep`, `Rsp` and `Cd`; relate each one to the explanation above. Do not try to connect the exported network to your body. It is a model exercise.

## 7. Sampling and filters

The initial sample rate is 250 samples per second **per channel**. Every sample is one row of simultaneous channel values; using more physical channels changes frame length, not the meaning of that row.

At 250 samples/s, the Nyquist frequency is 125 Hz. Frequencies above the useful sampled band must be sufficiently attenuated before they alias. A digital filter applied after a signal has already aliased cannot identify the original frequency from the aliased data alone.

The ADS1299 includes a third-order sinc decimation filter. Its response is not a perfectly flat brick wall [S1]. `model_filter_response.png` compares its nominal mathematical shape with our illustrative passive input circuit. The two traces represent different filters, not two competing estimates of one filter.

The time-domain generator uses a lower-rate, three-moving-average approximation to the sinc³ response. It is efficient for low-frequency lessons, but it does not simulate the chip's actual modulator bitstream, exact internal timing, or radio-frequency aliasing. The external passive circuit is a **separate exercise**, not automatically applied to the synthetic data. This separation is recorded in the metadata.

Our offline analysis uses a 1–40-Hz bandpass on individual candidate windows. This first lesson does not preserve slow DC behavior for interpretation, and it is not an ERP or real-time neurofeedback pipeline. Forward/backward filtering uses future samples; a live display needs a causal design and a latency budget.

## 8. What the plots mean

**Trace:** voltage versus time, displayed after removing the DC level. Always inspect raw offset/range information separately because a centered display can hide a serious DC problem.

**Power spectral density (PSD):** estimated signal power per unit frequency. A 10-Hz sine produces a peak near 10 Hz. The PSD is calculated with Welch's method [S5]. Units are explicitly shown; integrating µV²/Hz over Hz gives µV².

**Alpha-band power:** the integral between 8 and 13 Hz in this project. Band boundaries are analysis choices, not magical biological switches. The synthetic generator's main condition effect is deliberately placed at 10 Hz.

**Classifier score:** whether a simple model can recover the synthetic labels from band-power features in held-out sessions. The default case is intentionally easy. Perfect performance here validates only a limited part of the software path.

### Exercise: remove the answer from the generator

```bash
uv run --locked python run_lab.py demo --null-effect --out results/my_null
```

Now both labels have the same alpha-generation rule. In the recorded example, balanced accuracy falls from 100% to about 54%. One near-chance run is a useful negative control, not a proof that every possible source of leakage has been eliminated.

## 9. How we avoid a misleading machine-learning demonstration

The data are divided into synthetic sessions. A held-out session is never used to fit the model or the feature scaler. Windows from one session stay together. That follows the purpose of grouped validation and train-only preprocessing [S6, S8].

Features are only log band powers. Sample time, session ID, block ID and condition are not inputs to the classifier. Candidate windows do not overlap; filtering does not cross from one session into another. The artifact screen uses fixed rules before the condition is used for classification.

The pipeline also shuffles labels by **whole block within each session**, not by individual samples. Its 20 default permutations are only a quick diagnostic: the smallest possible reported permutation p-value is 1/21. That is not a publication-quality significance analysis or a guarantee of generalization to another person.

Our simple quality screen detects large excursions, flat channels, nonfinite samples and known simulated overrange. It can miss subtle muscle activity and other contamination. Artifact detection is a larger problem than one threshold [S7].

## 10. Why packets need more than numbers

A recording should tell you when data went missing. Each custom packet contains the physical channel count, gain, nominal rate, sample sequence, microcontroller time, an overrun counter, the ADS frame, and a checksum.

The checksum detects transport corruption in covered bytes; it does not prove the analog signal is right. It also cannot detect a wrong SPI value that the firmware already read and then checksummed. Sequence numbers expose missing packets. Timestamps allow checks of continuity and counter rollover.

Run the loopback exercise. Then examine `missing_before` in its CSV: it should flag the intentional losses. The spectral inspector refuses to join separated snippets into one apparently continuous waveform. Missing time is missing time, even when a smooth line would look nicer.

The packet format is specific to this lab. It is not an OpenBCI packet and cannot be assumed compatible with an unrelated board's stock firmware. Details are in [PROTOCOL.md](PROTOCOL.md).

## 11. A practical learning sequence

Spend the first session running the unmodified demo and matching each output to its source file. In the second session, change alpha strength, offset, and artifact size one at a time. In the third, change a passive component and compare predicted versus calculated response. Then repeat the packet-loss exercise.

Only after you understand those results should you choose the exact physical board. The next useful achievement is a reliable **internal test-signal recording from a powered board on the bench with no electrodes on anyone**, not a first unexplained line on your head.

The hardware guide gives the review gates. The experiment guide connects these measurement skills to your longer-term interest in perception and meditation without inventing a “consciousness score.”

References marked `[S#]` are linked in [SOURCES.md](SOURCES.md).

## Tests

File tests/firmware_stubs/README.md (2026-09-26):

# Host doubles for the actual sketch startup boundary

These minimal headers let `native_sketch_startup_test.cpp` compile and execute the
real `.ino` up to its first `SPI.begin`. They record software calls; they do not
emulate the ESP32, model electrical rails or validate peripheral behavior. The
Wi-Fi/UDP bodies exist only because the full sketch must compile; those paths
are not exercised or represented as transport tests.

The default reviewed-false header runs unchanged in the review-stop scenario.
Other scenarios change only a temporary copied header. There is no production
bypass macro and the real header must remain byte-identical after every test.
Fake time bounds infinite confirmation/halt loops. Each scenario has a separate
process, preventing state or serial replies from leaking between runs.

Seven scenarios cover the unchanged guard, no reply, prequeued replies, only a
fresh R, an early/queued V, both fresh replies and an injected GPIO latch failure.
Eight deliberate source mutations must compile and then fail behavioral checks:
remove the review stop, accept queued replies, skip the sequence, request the
wrong VCAP key, ignore GPIO failure, swap SPI MISO/MOSI, or use the wrong SCLK/CS.
The SPI double records all four initialization arguments before stopping; the
oracle checks the independent expected tuple (12, 13, 11, 10). They supplement—not replace—the timing
and pin-operation mutants in `test_firmware_startup.py`.

Run `uv run --locked python -m pytest tests/test_firmware_sketch_startup.py -q`
with g++ or clang++; missing compilers produce native skips, not execution
passes. The native CI job executes this through the existing `tools.check`
entry point; no new orchestrator or dependency is introduced. Real target
compilation remains the separate pinned Arduino/S3 workflow.

## Physical harness continuation

The actual-sketch suite now has eight normal scenarios (including legacy ESP32
review-stop) and twelve compiling mutations. Four console operations record
baud, frame format, RX and TX before the existing ADS startup events. Reviewed
S3 must explicitly use RX17/TX18; false-gate S3 and legacy keep their original
default route. New mutants swap pins, restore defaults, change baud or enable
the header console before review. No UART voltage/timing emulation is implied.

Standalone `tools.check --schematic` now requires g++/clang++ and reuses this
suite plus the CDC header checks before it publishes the physical harness. The
22 focused cases are part of, not additional to, the full native suite. All
route-defining firmware, these test/oracle inputs and stub headers are included
in its before/after snapshot. This closes the gap between declared constants
and the route the tested sketch actually calls. Actual S3 target compilation
and electrical interface qualification remain separate.

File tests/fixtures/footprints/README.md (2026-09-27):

# Frozen footprint sources, not assembly approval

Seven `.kicad_mod.gz` files are unmodified KiCad footprint sources from Debian
`kicad-footprints 9.0.2-1`. Copyright KiCad library contributors, CC-BY-SA-4.0
with the KiCad design exception; see LICENSE.md and retained file attribution.
https://gitlab.com/kicad/libraries/kicad-footprints

The two files under RevA_Passives.pretty are frozen project-authored T491 nominal
reflow footprints, under the project's MIT license, not KiCad upstream originals.
Gzip compression alone is applied with zero timestamps. Their editable sources
are in hardware/rev_a/kicad/RevA_Passives.pretty. Independent copper and courtyard
expectations follow KEMET Table 2; see docs/REV_A_TANTALUM_LANDS.md.

These are ordinary-test fixtures, not the production library. The native gate
reads actually selected installed and project-local files. The fixture helper
expands trusted version-controlled files into test directories without runtime
downloads or tar extraction. Source checks are not assembly qualification.

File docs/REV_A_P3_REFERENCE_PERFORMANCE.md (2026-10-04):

# P3 reference-check runtime: bounded exact-batch fast path

Base: `0719ba7e19eb4654aa4e43a862a8ffae0b32be9d`, tree
`cf437800d3915657fd86e500ebca64f5cada67e0`. This source preserves the complete
P3 connected copper and the pending-edge regression fix. It is **local and
unpublished** until a remote branch is read back; do not infer CI or review.
No PCB, circuit, BOM, firmware, carrier, dependency, electrical acceptance rule,
per-command timeout or shared 450-second CAD allowance changes.

## Why this optimization, not another timeout increase

The previous shared gate timed out at 450 seconds; its separately allowed
284-case diagnostic run took 505.58 seconds. Those results remain historical
fail/pass records, not rewritten. A fresh ordinary baseline in this session
passed 1232 tests plus 14 subtests. The unchanged 0719 CAD baseline then passed
284 cases in 364.18 seconds in a separate worktree. **The old timeout was not
reproduced in this environment.** A few brief focused probes overlapped that
baseline; it is a context measurement, not a controlled whole-suite benchmark.

Native profiling identified the P3 probe's repeated polygon subtractions: 1200
projections of 600 signal segments repeatedly processed the full ground-plane
polygon. The target reference has 8805 points, including fractured hole paths.
The profiled native subtract calls consumed about 1.18 seconds of a 1.43-second
probe. Other CAD checks and fresh native refill/DRC account for much of the full
suite; optimizing this kernel is not a promise of a proportionate suite speedup.

## What changed, and why the geometric acceptance is preserved

Group the **same exact full-width and 0.10 mm spine rectangles** by electrical
net. All rectangles retain the original integer-coordinate construction and
orientation. Subtract the same net-specific contact exclusions and the same
fresh reference-plane polygon from that group, using the pinned KiCad engine.
If and only if the result has **zero polygon outlines**, every rectangle in the
group is covered. Such a group needs no repeated per-segment subtraction.

Every nonempty group takes the original path: check each spine, calculate each
full-width gap, and reject growth outside the original pending envelopes on the
same net/layer. The per-segment 1e-6 mm2 numerical criterion is unchanged. There
is **no group area tolerance, contour simplification, tile clipping, sparse
point sampling, enlarged exclusion or reuse across board mutations**. Grouping
never crosses nets or the HOST/TARGET reference boundary. Layer/width/via checks
and the complete route inventory still execute even for an empty group.

This is the set relation: if `(union of query rectangles) - permitted copper`
is empty, the difference for each rectangle is empty. Nonempty results are NOT
assumed bad or good in aggregate; they fall back to the previous individual
checks. Because native polygon semantics matter, a regression explicitly checks
nested/duplicated full-width and spine outlines around a small central void;
that void must not disappear by an even-odd overlap cancellation.

The geometry kernel remains `uncovered()`, operating on the whole native ground
reference. The new audit independently reruns it for all 1200 projections and
requires the exact same 18-record gap inventory. This is a differential check
against the preserved kernel, not an independent electromagnetic model. Existing
pending gaps remain electrically unapproved and their file/hash are unchanged.

## Observed failure-first and equivalence evidence

Test commit `80c112a` observed two failures on the old probe: excessive repeated
native polygon work, and a changed new audit file missing from the schematic
input snapshot. The implementation commit `0fe282f` addresses both. The snapshot
contains 92 entries rather than 91 solely because that new source file is now
included. The whole 43-case focused audit/gate selection passed afterward.

The deterministic work assertion counts vertices passed as right-hand operands
to actual native subtraction calls (including batch preparation). Original:
10,618,414; optimized: 3,280,208, a 69.1% reduction for the canonical board. It is
a work proxy, not a CPU instruction count or runtime guarantee. The assertion
requires no more than half the naive repeated reference work, avoiding a flaky
wall-clock test. No native check result is cached across processes.

A separate preserved-old-script/new-script comparison used the SAME freshly
refilled board copy for each pair. Five fresh processes per version, alternating
order, gave median 1.4502 seconds before and 0.6345 seconds after (about 2.29x).
All ten JSON results matched. Eight further native board variants matched both
acceptance and failure class: reverse, split, remote-void, reference-void,
edge-growth, edge-remote, reverse-residual and split-residual. Each of those
variants was freshly refilled and had DRC parity/other/unconnected = 0/0/0; the
intended reference void and edge growth still failed their reference checks.

During authoring, passing a borrowed outline from a temporary SWIG parent caused
a native crash; retaining the rectangle while copying its outline fixed object
lifetime. A helper-name collision was also corrected before the implementation
commit. Those attempts are retained as failures, not reported as passing tests.
A scratch contour-unfracturing experiment changed geometric differences slightly
and was rejected; it is not part of the committed solution.

## Reproduce and next step

```sh
uv sync --locked --all-extras
uv run --locked --all-extras python -m pytest tests/test_reference_performance.py tests/test_schematic_gate.py
uv run --locked --all-extras python -m tools.check --schematic
```

The source checkpoint stores paired timings and counts; final shared-gate
outcomes must be read from their actual tested head, not inferred from these
focused results or the historical diagnostic run. The new native audit is
included alongside ALL 284 inherited CAD cases, not in place of any of them.
No full native integration, S3 build, hosted CI, independent reviewer or physical
experiment follows from this local runtime work.

Next is normal authorized publication of the full retained history, exact-head
hosted checks and a separate electrical/layout review. Automated publication
workflows were previously blocked and were not retried or bypassed in this
slice. Do not rebuild P3 copper. Keep its 18 pending edge records, long supply/
clock/control paths, sense coupling, stackup, #45/#48, complete delivered budget
and all fabrication/purchasing/powered-connection/body-use restrictions open.

Native polygon API reference (cross-checked with the installed 9.0.2 binding):
https://docs.kicad.org/doxygen/classSHAPE__POLY__SET.html

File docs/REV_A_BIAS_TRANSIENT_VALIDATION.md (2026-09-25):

# Independent BIAS transient validation (PR #23)

The earlier BIAS studies compared complex frequency-domain responses with
ngspice, but their step traces came only from Python matrix exponentials.
This increment checks the **time-domain implementation independently** before
adding any nonlinear overload behavior. It does not change the stated circuit.

## Experiment and reference

A 1 nA step is applied to the electrical dummy-common node. All capacitor
voltages start at zero relative to the local analog midpoint. This is a
zero-state interference experiment, **not supply power-up or a person test**.
`uic` prevents ngspice from initializing at the final DC operating point.

The existing full 12/13-state descriptor provides the independent solution
`x(t) = x_inf - exp(A*t)*x_inf`. Public `step_voltages` returns dummy-common
and amplifier-output volts; `step_response` retains its previous common-only API.
No differential-transfer, component or amplifier parameter was changed.

Seven stable configurations are checked: balanced, asymmetric, open input,
open BIAS, and the three existing extra-pole cases. The unstable high-impedance
stress case still has **no settling trace**. Existing 16 AC comparisons remain.

The generic `run_ngspice_transient` API shares the original bounded ngspice
subprocess implementation. It requires fresh output, finite real columns and
strictly increasing nonnegative times, retains timeout/error logs, and rejects
missing, stale, malformed, one-row or nonfinite tables. It does not itself
certify circuit correctness or that a requested time window was completed.

## Numerical controls and retained data

The generated BIAS transient uses trapezoidal integration, a 1 ns suggested
initial increment and a **200 ns maximum internal step**, over 0–100 ms.
Only common/output vectors are saved. ngspice `linearize` exports a uniform
**2 us interpolated observation grid**, limiting retained table size. That
50,001-row table is not the raw adaptive integration history. The netlist and
log preserve the integration/export instructions.

The completion gate compares selected early-time and whole-window rows against
matrix exponentials with fixed `rtol=1e-4`, `atol=1e-9 V`. It retains maximum
absolute errors, point counts and tolerances in `native_step_comparison`.
A successful comparison is not a claim about every unobserved instant.

Initial 2 us/Gear experiments failed these same tolerances, especially with the
slow extra pole. Refining the integration and initial increment corrected the
numerical disagreement without fitting the circuit or loosening acceptance.
A native regression additionally halves the maximum step to 100 ns for the
100 Hz extra-pole case, requires reduced error against the analytical trace,
and repeats the original accuracy check. A separate 1 kohm / 1 uF RC fixture
checks the process/reader path against `1-exp(-t/1 ms)` at a 1 mA input step.

The ngspice manual describes `.TRAN`/`uic`, transient integration options and
`linearize` in sections 11.3.10, 11.1.4 and 13.5.45:
https://ngspice.sourceforge.io/docs/ngspice-manual.pdf . The actual authoring
checks executed ngspice 42; compatibility was tested, not inferred from the
current manual alone.

## Failure and history evidence

Test-only commit `443fa40190728c1ea7ef184df7001a50b7f731b4` in PR #23 requires
an executable step export. It fails against the previous `loop|closed` exporter;
CI run `36172743628` retains that missing-feature evidence. This is not a claim
that the previous AC solver contained a numerical defect.

Software-only fixtures deliberately inject disagreement, late-start and
truncated-time traces. They cannot publish a completion manifest and never
claim native execution. Real native tests and the full study run are separate.
The final exact-head quality/native CI, not this description, is merge evidence.

Current complete study output has 16 AC netlists and seven step netlists;
seven step tables/logs exist only when native execution was requested. All
are bound by the existing last-published manifest. A transient failure leaves
partial evidence but no completed generation. Prior run directories are intact.

No output rails, slew/current limit, saturation/recovery, startup sequence,
physical contact measurement, firmware enablement or safety approval is added.

Subsequent completion hardening requires `expected_stop_s=0.1` when the study
reads native output. A fresh `transient-window.txt`, written before `linearize`,
records the raw integration endpoints and is included in the file manifest.
Exported endpoints alone are insufficient: interpolation can extend the displayed
window after a shorter integration. The overload study's actual truncated-run
regression demonstrated a numerical false pass; the separately probed linear
step truncation did fail its numerical comparison. No claim is made that this
linear reference itself was observed falsely passing that probe.

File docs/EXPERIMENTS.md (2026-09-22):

# Experiments: building evidence rather than collecting attractive traces

Your interest in consciousness and meditation can motivate this project without requiring the first experiment to answer a philosophical question. The useful first questions are smaller: can you recover a known signal, distinguish it from interference, and repeat a controlled observation?

**The body-connected experiments below are future protocols, conditional on the hardware review in HARDWARE_GUIDE.md. They are not instructions to attach the current unreviewed circuit.** The supplied data and classifier are synthetic only.

## Experiment 0: a signal whose answer you know

Run `python run_lab.py demo`. The generator builds six sessions with randomized, balanced condition blocks. One label receives a larger 10-Hz component. It also adds other rhythms, colored noise, residual 50/60-Hz interference, offsets and occasional artifacts.

Before looking at the result, predict which condition should have more 8–13-Hz power. Open the spectrum and the JSON report. The measured increase confirms that this limited software path can recover a deliberately planted effect. It does not confirm that the synthetic signal is a realistic model of meditation.

Then run `--null-effect`, change the random seed, change channel count, and increase artifact size. Keep each result in a distinct output folder. A notebook that records settings, predictions and outcomes is more useful than a folder of unlabeled screenshots.

## Experiment 1: deliberately damage the measurement

Set the differential offset beyond the gain-dependent range. The correct outcome is rejected/overrange data. A smooth filtered waveform is not the goal.

Run `python tools/run_loopback.py`. Confirm both deliberate packet losses are reported. Try a manual replay with frequent drops: the inspector may have no uninterrupted four-second interval and therefore no spectrum. Treat that as an informative failure.

Change the electrode impedance model. Observe how common-mode interference turns into a differential error. Keep the distinction between this passive circuit result and the synthetic recording generator: they are separate exercises in this release.

## Experiment 2: hardware, but still no head

With a reviewed assembled board and target-compiled firmware, record the internal test source, then internal short. Save raw binary, decoded CSV, metadata JSON, firmware revision, clock/reference assumptions and a note of the physical setup.

Move digital wiring or change the radio setting one factor at a time, while remaining on the bench. Check packet continuity and spectra. Do not assume a noisy radio setup can be corrected later with a classifier.

A future external-dummy calibration requires board-specific input/common-mode and protection review. Passing internal test and short establishes only part of the signal chain.

## Experiment 3: a future posterior-alpha observation

After the body-interface gate is satisfied, a modest first physiological target is a repeated comparison of eyes open and eyes closed using a posterior recording channel. OpenBCI's EEG guide uses this kind of alpha observation as an accessible demonstration [S12]. It is a better initial target than inventing a direct measure of consciousness.

A proposed learning protocol is twelve 30-second blocks, six in each eye condition, in a balanced randomized order. This block count is a practical starting design, not a statistical power calculation. Stay comfortably seated, keep the head and jaw relaxed, and use a stable setup. Record condition onsets, uncertainty in timing, electrode montage and contact preparation. Mark transitions and exclude a predefined settling interval before analysis.

Choose the exact montage/reference/bias connections from the reviewed board documentation, not from this generic description. O1/O2 are standardized posterior location names, not arbitrary labels for “somewhere at the back.” Proper placement and reference details matter.

Specify the analysis before inspecting the results: an 8–13-Hz band-power comparison across clean blocks, a quality rule, and how transitions and artifacts are excluded. Keep all blocks, including those that fail quality checks, in the record. Report the number rejected in each condition. Inspect raw voltage, spectral content and quality information together.

An increase after eye closure may be a useful repeatable physiological observation. Its absence in one attempt does not establish that your brain is abnormal, nor does its presence establish that every channel is good. Eye movement and muscle signals can dominate recordings; MNE documents these artifact families [S7].

## Experiment 4: meditation versus quiet rest, with the eyes held constant

Do not compare eyes-open ordinary activity with eyes-closed meditation and call the difference a meditation effect. That design changes too many things at once.

A proposed within-person pilot is six two-minute blocks per session: three meditation blocks and three quiet-rest blocks, with the **same eye condition** in both. Balance order across sessions and use ordinary comfortable breathing rather than deliberately changing respiration. Keep posture, instructions, room and recording setup as constant as practical. Run on at least three separate days as an exploratory start; this is not a claim of sufficient statistical power.

Write down one primary outcome beforehand, for example the difference in median log posterior alpha power between conditions. Other bands can be exploratory rather than retrospectively promoted to the original hypothesis. Record subjective ratings after blocks: perceived stability of attention, drowsiness, effort, discomfort and perceived depth. These are separate observations, not ground truth derived from the EEG itself.

The first result should be an effect estimate and the spread across blocks/days, with quality exclusions visible. A classifier is optional. A non-significant, unstable, or artifact-dependent result is still useful information about the measurement and protocol.

## Experiment 5: a classifier that faces a meaningful test

Start with a simple model, not a deep network. Keep all windows from a day together, fit scaling only on training days, and hold out a complete day. Do not randomly mix nearby or overlapping windows between training and test sets. The supplied synthetic example implements the same basic group-separation principle [S6, S8].

Check a majority-class baseline, shuffled whole-block labels, and whether predictions correlate with artifacts, time in the session, electrode quality or recorded movement. A model that learns a jaw-tension habit can predict your labels while answering the wrong scientific question.

The existing `demo` classifier is **not** automatically applicable to a real capture CSV. It expects a validated labeled synthetic dataset with session/block information. Real data need a separate import/annotation path, accurate events, montage/reference metadata, artifact review and appropriate validation. The bench `inspect` command computes unlabeled signal-quality summaries; it does not infer meditation.

## What would justify a stronger claim?

A credible next claim is specific: “Under this montage, protocol and quality rule, this participant showed a repeatable difference in a prespecified measurement across these sessions.” That is much narrower than “this device measures consciousness.”

Keep alternative explanations visible. A small scalp-recording system and a label classifier alone do not identify a unique mechanism of consciousness. The project can nevertheless teach the practical science needed to ask increasingly precise questions about perception, attention and subjective experience.

## Minimal experiment record

Use a text file beside every recording with: session/date; device and firmware revision; gain/reference/sample rate; montage; condition schedule; timing method; electrode preparation; battery/wireless arrangement; raw-data filename; packet-quality summary; exclusions; and subjective notes. Avoid uploading identifiable raw recordings or private notes to public services without considering the privacy consequences.

Use `experiment_record_template.md` as a starting point. A future assistant should receive the protocol and quality record, not only the most attractive plot.

References marked `[S#]` are linked in [SOURCES.md](SOURCES.md).

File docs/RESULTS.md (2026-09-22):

# Results report: ADS1299 Learning Lab

**Release check: 19 September 2026.** This report distinguishes software execution, numerical modeling, external simulator execution, target compilation and physical validation. They are not interchangeable.

## Outcome

A runnable, hardware-free ADS1299-oriented learning project was created and exercised. It includes source code, regression tests, synthetic recordings, circuit-model outputs, a real localhost transport exercise, an offline visual guide and a conditional hardware progression.

**Final regression result: 65 passed, 0 failed, 0 errors, 0 skipped.** This result covers the included tests. It does **not** count unavailable ngspice execution or ESP32 target compilation as successful tests; those checks have separate explicit statuses.

No physical ADS1299/ESP32 board was connected, no human EEG was recorded, and no body-connected circuit was approved. The exact hardware and a complete under-$100 purchasing solution remain unresolved.

## Verification matrix

| Area | Actual result | Evidence and boundary |
|---|---|---|
| Python regression suite | **65 passed** | `../results/validation/pytest.log` and `pytest.xml`; covers the layers below. |
| Python syntax compilation | Completed | `python -m compileall -q lab tools tests run_lab.py`. |
| Ideal ADC scaling and limits | Tested | Signed-code endpoints, quantization, range and common-mode checks; not measured chip accuracy. |
| Passive input-circuit solver | Executed | Independent nodal calculation, limiting-case tests and 200 tolerance trials. |
| Actual ngspice | **Not run** | Binary unavailable; installation attempts unsuccessful. Strict command exited nonzero rather than claiming a pass. |
| Synthetic analysis | Executed | Default and null-control raw datasets, reports, quality CSVs and example figures. |
| Real localhost UDP | Executed | 2,248 received packets; both deliberate missing samples detected; no physical radio involved. |
| Portable firmware helpers | Native C++ compiled/tested | CRC, signed 24-bit conversion and packet output matched Python byte-for-byte. |
| Complete ESP32 sketch | **Not target-compiled or hardware-tested** | ESP32 toolchain unavailable. Portable C++ success does not validate the whole firmware. |
| Visual-guide arithmetic | Executed under Node | Valid/invalid gain-offset-common-mode examples tested. |
| Visual-guide browser rendering | **Not run** | Playwright installed, Chromium executable unavailable. HTML is not described as browser-render-verified. |
| Physical power/protection/bias | **Not tested** | No board identified or present. |
| Physiological EEG / meditation | **Not measured** | All provided recordings are explicitly synthetic. |

The authoritative machine-readable record is [VALIDATION.json](../VALIDATION.json). See [CHANGELOG.md](../CHANGELOG.md) for the initial 55-test run, the expanded check/fix and subsequent runs.

## Default synthetic experiment

Configuration: seed 42; four channels; 250 samples/s/channel; six sessions; eight 12-second blocks/session; gain 24; nominal 4.5-V code reference; 30-mV illustrative differential offset. The generator creates 576 seconds total (144,000 simultaneous sample rows), not six independent people. It deliberately makes 10-Hz amplitude larger for the “eyes-closed” label.

| Measurement | Observed output |
|---|---:|
| Candidate four-second epochs | 96 |
| Accepted epochs | 78 |
| Rejected epochs | 18 |
| Median alpha power, open label | 12.2097 µV² |
| Median alpha power, closed label | 136.0573 µV² |
| Ratio of those medians | **11.1434** |
| Session-held-out balanced accuracy | **100%** |
| Majority-class baseline balanced accuracy | 50% |
| Mean of 20 whole-block label permutations | 52.0199% |

The accepted set contains 42 open-label and 36 closed-label epochs. Every test fold is a completely held-out synthetic session. A standardization/model pipeline is fitted only on the remaining sessions. Conditions, time and session IDs are not classifier features.

The 100% result is expected for an easy **planted** effect. It establishes neither real EEG accuracy nor consciousness decoding. The 20-permutation p-value is 1/21 in this run: too coarse to present as a serious scientific significance result.

Evidence: [analysis JSON](../results/demo/analysis_report.json), [epoch-quality CSV](../results/demo/epoch_quality.csv), [event CSV](../results/demo/events.csv), [raw synthetic NPZ](../results/demo/synthetic_recording.npz).

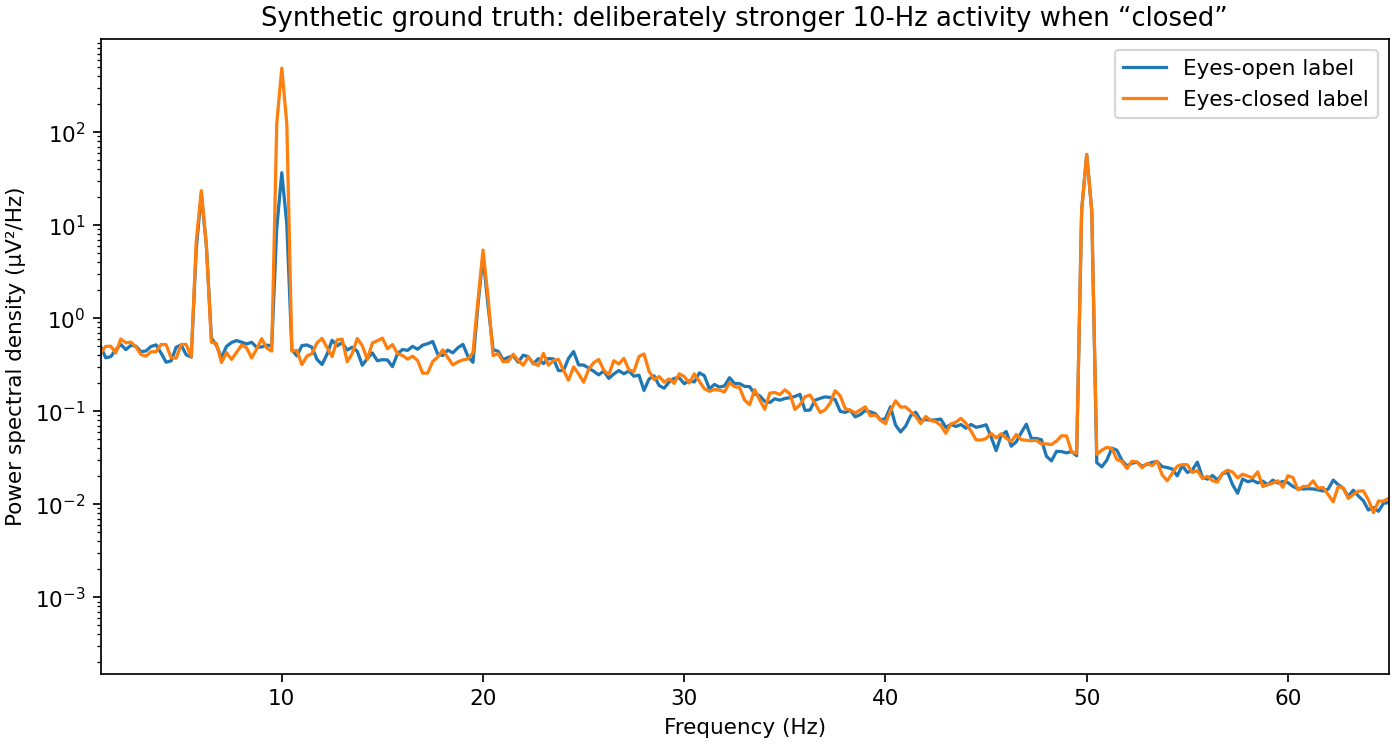
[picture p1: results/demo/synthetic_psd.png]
Synthetic PSD: intentionally different 10-Hz activity, not human data


## Negative control: remove the condition effect

The same generator was rerun with `null_effect = true`. The labels no longer control alpha amplitude.

| Measurement | No-effect result |
|---|---:|
| Accepted / rejected epochs | 78 / 18 |
| Closed/open alpha-power ratio | **1.0268** |
| Session-held-out balanced accuracy | **54.1667%** |
| Baseline balanced accuracy | 50% |
| Mean of 20 block-label permutations | 49.9517% |

This is a useful negative control: the software does not produce perfect label recovery when the intended effect is absent. One finite near-chance result does not prove the absence of every possible leakage route. Raw data and the complete report are retained in [results/null_control](../results/null_control/analysis_report.json).

## Numerical circuit exercise

The illustrative two-input passive network passed analytical limiting-case/symmetry checks and was evaluated across frequency. This is **our own frequency-domain nodal solve**, not ngspice and not an ADS1299 silicon model.

Observed numerical outputs:

| Quantity | Model result |
|---|---:|
| Balanced differential gain at 10 Hz | 0.9998940 V/V |
| Common-to-differential conversion at 50 Hz with one contact changed from 10 kΩ to 50 kΩ | 0.00063843 V/V |
| Differential amplitude for 100-mV common-mode amplitude in that mismatched example | **63.8431 µV** |
| Independent tolerance trials | 200 |
| 10-Hz differential-gain range across those trials | 0.9998859–0.9999002 V/V |

Resistors were varied independently over ±1% and capacitors over ±5%, with uniform distributions. These are chosen uncertainty assumptions, not measured production yield. Perfectly balanced common-mode conversion is approximately numerical zero due to symmetry; it is not evidence of infinite real-system CMRR.

No body-bias loop, thermal noise, protection device, PCB parasitic or supply fault was simulated. These component values must not be interpreted as approved patient-protection values. The synthetic recording pipeline does not automatically include this network; the exercises are explicitly separate.

Evidence: [circuit report](../results/circuits/circuit_report.json), [response CSV](../results/circuits/circuit_response.csv), [tolerance CSV](../results/circuits/tolerance_trials.csv), and generated `balanced.cir` / `mismatch.cir`.

The strict external command was attempted:

```text
python run_lab.py circuits --out results/strict_spice_attempt --require-ngspice
exit code: 2
reason: native SPICE required but ngspice unavailable
```

Log: [strict_spice_attempt.log](../results/strict_spice_attempt.log). When ngspice becomes available, rerun that command and inspect its numerical comparison rather than updating this report by assumption.

## Actual localhost recording test

`python tools/run_loopback.py` started a real UDP receiver and transmitted a nine-second synthetic sample schedule at a nominal 250 SPS. Sample sequences 1000 and 2000 were deliberately not sent.

| Quantity | Observed result |
|---|---:|
| Scheduled sample positions | 2,250 |
| Valid received packets | **2,248** |
| Detected missing samples | **2** |
| Duplicates / stale packets / timing anomalies | 0 / 0 / 0 |
| Uninterrupted four-second PSD windows | 1 |
| Spectral peak in every channel | **10 Hz** |

The receiver, binary storage, decoder, gap handling and spectrum calculation all ran. The payload and device timestamps were generated in software. This does not establish ESP32 Wi-Fi throughput, actual clock accuracy or SPI acquisition reliability.

Evidence: [LOOPBACK_REPORT.json](../results/loopback/LOOPBACK_REPORT.json), binary capture, decoded CSV, metadata and quality report in `results/loopback`.

## What the tests check

The test suite includes signed 24-bit extremes; quantization and voltage units; nominal filter response; input/common-mode limits; passive-circuit symmetry and analytical limits; CRC corruption and stream resynchronization; sequence/timestamp rollover; gaps, duplicates and order; configuration consistency; deterministic generation; known-sine power; artifact/overrange rejection; held-out sessions; six/eight-channel and 500-SPS cases; null-effect behavior; gap-safe inspection; native C++/Python agreement; CLI behavior; the bench-only default gate; and the visual calculator's arithmetic.

These checks establish that the included components behave as tested. They are not an exhaustive proof of every input, dependency version or platform. The clean installation, full ESP32 build, external simulator and physical board stages still need their own evidence.

## What is delivered, and what is not

Delivered: reusable software, generated evidence, ordinary SPICE exports, a conditional bench starter, a visual explanation and a documented route to hardware.

Not delivered: manufacturing-ready Gerbers, a reviewed complete board schematic, guaranteed under-$100 assembled hardware, target-compiled firmware, external-electrode acquisition firmware, a fault-current assessment, an approved wearable instrument or real brain measurements.

The practical next step is to identify the exact ADS1299 board and ESP32 model while working through the hardware-free exercises. The hardware guide explains why the power and electrode connections cannot yet be made into a truthful universal plug-by-plug picture.

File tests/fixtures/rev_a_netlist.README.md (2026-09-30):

# Frozen native export, not fresh CAD evidence

These fixtures are unmodified KiCad 9.0.2 XML/CSV exports from the K1 header
migration on 2026-09-30. XML is compressed with gzip only for size. They support
ordinary parser/topology tests; historical paths/timestamps are not a new
validation run. The native gate re-exports each tested checkout and compares its
complete parsed graph with this fixture. No fixture authorizes hardware use.

## K1 current capture

Only J_DIG/J_INPUT Value and MPN differ from the previous parsed graph:
`TSW-110-07-T-D` -> `HTSW-110-07-T-D`. All nets, pin types/functions, footprints,
other properties and 67 other component records are unchanged. The CSV remains
69 rows, including eight DNP packages and the off-board controller. Both outputs
were generated by the actual native CLI and checked with the existing validators,
not edited into an invented export. See `docs/REV_A_CONNECTOR_K1.md`.

Uncompressed XML SHA256: `c770d07dadc08ff458a18daa5d0fa3a589a6178da0d4bcb9ebbc57e0a1f00ea0`.
CSV SHA256: `1b00ddf0be1a3743da00eb88cd93060816741afd794f12903ec7910827b035fa`.

The prior 2026-09-27 T491-land export (XML ca9ccef463e1ab31426ae3afdc9744bd085a6b5bfde18fe231871228ce91fea2,
CSV 87460b3c87d06f3ad077e5521f7b06665c0a19cd4e16f3d25169e1603e2c3c22)
and earlier PR43 captures remain in Git history. Their historical facts are not
rewritten. Current fixtures are not physical capacitance, fit or process tests.

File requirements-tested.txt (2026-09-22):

# Exact versions used for the recorded Linux validation.
numpy==2.3.5
scipy==1.17.0
matplotlib==3.10.8
scikit-learn==1.8.0
pytest==9.0.2

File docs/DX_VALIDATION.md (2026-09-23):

# DX validation record — 2026-09-23

This is a dated software/native-integration result, not hardware approval. The original `VALIDATION.json`, `results/`, `docs/RESULTS.md`, and `requirements-tested.txt` are retained as historical evidence.

## Executed snapshot

Source commit: `3dff928aa3fe042ab626b2b24ba64cea7a01e399` on `dx/quality-foundation`.

Verified GitHub Actions run: [Quality #4 — run 35913793737](https://github.com/utof/eeg_ads1299_lab/actions/runs/35913793737), completed successfully on 2026-09-23.

All three jobs passed: `Python 3.11 quality`, `Python 3.13 quality`, and `Native integration`. Both Python jobs installed the project and development tools from `uv.lock` with `uv sync --locked --all-extras`. These were Linux runners; this record does not claim macOS or Windows CI coverage.

The native job used Python 3.13.15 and ngspice 42. Its logged shared gate results were:

| Check | Observed result |
|---|---|
| Ruff format | 55 files already formatted |
| Ruff lint | All checks passed |
| Pyrefly strict, minimum severity `warn` | 0 diagnostics |
| complexipy | No function with cognitive complexity greater than 15 |
| Tach | All modules validated |
| Static hardware baseline | PASS; explicitly not hardware or safety validation |
| Software tests | 140 passed, 3 deselected, 5 subtests passed |
| Native/integration test selection | 3 passed, 140 deselected |
| Measured branch coverage | 261 / 360 = 72.50%; configured floor 71.00% |
| Combined line/branch figure printed by coverage.py | 83.61%; not the branch-only ratio |

The two pytest selections cover 143 tests without counting the software tests again just because multiple CI jobs ran them. The 90% core branch-coverage target is future work, not an achieved result.

## Actual simulator and transport execution

The strict circuit command ran ngspice and reported `executed_and_compared` for the **existing educational passive network**, not the next Rev A-specific model. Maximum absolute complex-response differences against the independent nodal solve were:

- Balanced differential case: `4.502029904938123e-16`.
- Mismatched common-mode case: `1.6666753876341406e-15`.

Those are numerical agreement measurements for this linear model and solver pair. They are not measurements of a physical ADS1299, a BIAS-loop stability result, or a safety guarantee. The existing illustrative component values remain distinct from the selected Rev A component contract.

The longer real localhost UDP replay accepted **2,248 packets**, detected **2 deliberately omitted samples**, and found **one intact four-second spectral window**, with a 10-Hz synthetic peak in all four channels. The native tests also exercised the portable C++ transport helper and Node arithmetic checks. None is an ESP32 target firmware compilation.

The run uploaded JUnit XML, coverage, per-check logs, simulator netlists/output/logs, and loopback reports. In particular, the `native-integration` artifact is [artifact 10774490821](https://github.com/utof/eeg_ads1299_lab/actions/runs/35913793737/artifacts/10774490821). Artifact retention is 14 days, so rerun CI when fresh downloadable evidence is required; a retained Markdown summary is not a substitute for a new execution.

## Failure-first evidence and recovery limits

The interrupted source transfer was recovered by checking old/new content hashes before writing the recovered entries. The first independent recovery audit at source `b374c349b0145bac65ef3b7b53cdadad9fe72539` correctly failed: the missing `tools.check` implementation caused test collection, architecture, and type-check failures, and the unfinished utility scripts failed lint/type checks. See [recovery audit 35913194799](https://github.com/utof/eeg_ads1299_lab/actions/runs/35913194799).

The missing tools were completed, the existing runner tests passed, and a subsequent observed E402 failure was fixed by removing the loopback script's `sys.path` workaround and using the installed package imports. No checker was disabled to resolve those failures. This records observed red/green evidence; it does not prove the test-first chronology of every line originally recovered from the interrupted session.
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

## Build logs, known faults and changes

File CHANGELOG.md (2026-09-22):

# Build and verification notes

## Initial implementation

Created the ADC model, passive circuit solver/exporter, synthetic signals, grouped analysis, custom transport, bench starter and tests. First regression run: **55 passed**. Log: `results/initial_tests.log`.

## Expanded checks and inspection

Added six/eight-channel and 500-SPS pipeline checks, a no-effect negative control, gap-safe capture inspection, and bench-gate regression checks. Improved the sketch's error halt to assert PWDN: keeping START low alone does not cancel command-started conversion.

The first expanded run had **one test failure and 62 passes**. The failing assertion was an overly literal whitespace-sensitive check of the existing `BOARD_PROFILE_REVIEWED = false` declaration, not an enabled hardware gate. The assertion was corrected to ignore spaces. The next expanded run passed all **63 tests**. Both logs are retained.

## End-to-end execution

Ran the default and null-control pipelines. An initial notebook-triggered run encountered output-directory permissions; permissions were corrected and the complete demo and figures were regenerated successfully. A notebook subprocess startup hook also emitted an unrelated spreadsheet-runtime warning; direct execution of the lab avoided that hook. These environment incidents are not presented as EEG-model validation.

Ran a real localhost receiver/replay/decode/inspection exercise. Sent a nine-second synthetic schedule with two deliberately missing sample sequences; received 2,248 valid packets and identified both gaps. No physical microcontroller or ADC was used.

## External tools

ngspice and the ESP32 target build toolchain were absent. Installation attempts did not succeed in this environment. The package retains explicit unexecuted statuses and strict commands that fail rather than silently treating those checks as passed.

The final test counts and tool statuses are in `VALIDATION.json`; later tests may increase the count beyond the intermediate logs above.

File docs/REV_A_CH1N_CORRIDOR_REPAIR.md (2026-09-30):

# CH1N source-corridor repair

## Scope and identity

This continues the input review in PR #65, from main
`779b8efaa0c5e1b84cdbee49a07b053e3debe7b7`, tree
`0a2e5eabd627dbabd26706e046540f44ab9852f6`. It edits the authored PCB, never the
parking-grid importer. The repair branch is `fix/ch1n-corridor`; inspect its
live PR/head/checks/review until merged, then use current main.

The board SHA256 changes from
`232b7c68a63ae13aebcf71f8c0b1f210421c30452a1afc7b7c86dc1c118b23a3` to
`5da65b4307f0336883da9aeae48711b28c1944ec587f5d3174f12db4e9921875`.
`checkpoints/20260930_ch1n_corridor.json` records exact removed/added forms,
itineraries, preservation checks, and remaining crossing locations. This is
geometric design evidence, not extracted capacitance or physical qualification.

## The actual change

CH1N_DUMMY still connects J2.2 to R2.1. Its middle corridor moves out of the
DNP-branch region to x=34.9 mm on In2. The entry is front copper to a via at
(31, 30.75); the inner path runs above the input bank, down its right side,
then back to the existing via at (31.7, 43). The original final front connection
to R2 and that second via remain byte-identical. No footprint moves.

This removes all four previously identified CH1N B/In2 projected overlaps:
IN2P, IN3P and IN4P branches to DNP diode pads, plus CH3N_DUMMY. The native
full-width screen finds no overlap between this net's In2 traces and any
foreign back-layer track or pad. The eight main R/C/U1 itineraries and every
DNP branch remain unchanged. DNP devices are still unpopulated; no protection
or filter redesign is implied.

The complete input crossing inventory drops from 13 to 9 unique net-pair
locations (22 to 18 raw segment pairs). The remaining three CH2N/input overlaps
and six AVDD/input overlaps are the same previously recorded locations, not
new crossings or automatically accepted coupling performance. See the JSON.

## Why this is not an all-front route

Existing front routing obstructs a compact all-front connection. A disposable
0.025-mm grid trial found a roughly 47.8-mm front route around the header; that
trial is not a proof of the globally shortest possible layout. Another tested
32.4-mm F/In2 candidate threaded front copper between other channels' resistor
pads. The selected route avoids that new front-layer adjacency, at the cost of
about 1.5 mm more trace than that candidate. No unrelated copper was pushed.

| CH1N authored trace sum | Before, mm | After, mm |
|---|---:|---:|
| F.Cu | 10.882 | 15.296 |
| In2.Cu | 12.597 | 18.588 |
| B.Cu | 0 | 0 |
| Total | 23.479 | 33.884 |
| Through vias | 2 | 2 |

**The route is longer by 10.406 mm.** It is not a timing, noise or length-matching
improvement claim. The In2 span is a deliberate corridor, not described as a
short local escape. In1 ground faces both F and In2; at the crossing-free new
In2 corridor there is no foreign B track immediately underneath. Where it
projects across other channels' front fanout, In1 is physically between them.
This removes the specific overlap arrangement without claiming zero fringing,
parallel-route coupling, package/cable effects or a qualified stackup.

The two vias are physical F-B through vias connecting F/In2 traces. Unused barrel
parts are not extracted. No blind vias, plane split, blanket stitching, matching
meanders, component/value changes or new layer assignment are introduced. The
In1 filled ground remains one region, but that alone is not proof of a good
return path. Dielectric spacing, actual source spectrum and physical performance
remain unresolved. Do not map these lengths to picofarads or measured CMRR.

## Preservation and native checks

Exactly nine old segments and one old via are removed; seven segments and one
via are added. All 68 footprint forms and 696 retained track/via forms remain
byte-identical, including the last two CH1N front segments and resistor-side
via. The other non-zone board forms and zone source settings are unchanged;
only the native-filled polygon changes. There are now 582 segments, 122 vias,
68 footprints and 245 pads. New tracks are 0.20 mm; the new via is 0.60/0.30 mm.
No signal tracks were added on In1. No schematic, BOM, firmware, model, dependency,
clearance, severity, exclusion or approval gate changes.

Raw source and native item coordinates/nets/layers/straight-segment lengths were
cross-checked for all 704 track/via items. The old and new main-input itinerary
items are byte-identical. A separate determinant centreline screen re-enumerated
the nine remaining crossing locations. These checks complement, not replace,
native refill, parity and DRC. They are analysis checks, not extra project tests.

## Test-first policy and fault controls

Test-only `3f75b5e2b33b04b239be6c7c549bac32e0d6f59d` preserves one intended native
failure on the unchanged board: the new CH1N policy sees four foreign back-layer
partners and 0.012736 mm2 of uncovered trace projection, while ordinary native
DRC still reports 0 parity / 0 other / 0 unconnected. The two existing CH1N
connectivity/cut cases selected alongside it pass. This is one new failing
case, not three failures.

The new guard lives in the already-snapshotted `tests/test_pcb_placement.py`.
It allows only F/In2 routing, at most two vias, no positive-area In2/foreign-B
copper overlap, and full-width projection onto the fresh single In1 filled
region. Native integer polygon Booleans include full trace shapes, not just
centreline samples or arc endpoints. The tiny residual-area limit is the
existing output screen's 0.00001 mm2 geometric tolerance, not a noise limit.

Only CH1N's own through-pad and via clearance shapes are exempted from the
reference mask: the actual zone clearance of 0.25 mm plus 25 um approximation
margin, with native shape error 5 um. Those physical openings still exist. No
foreign hole or added reference window is waived. Ground copper outside the
filled zone is not added to this mask, so the screen can conservatively reject
geometry needing explicit review. It does not evaluate every parasitic field.

The first proposed corridor passed DRC and removed the overlaps but failed the
reference guard at a neighboring via-clearance edge. Moving its inner vertical
run outward corrected the copper, without relaxing the mask or tolerance.
The selected route then passed the complete new focused set:

- One canonical CH1N policy case.
- Three harmful, still-connected native copies: restore the original crossing
  route; move the new inner corridor to B; add a small In1 pour window beneath
  the inner corridor. Each freshly refills and passes ordinary DRC, but fails
  the intended policy.
- Three accepted controls: reverse endpoints, subdivide a trace, and put the
  same small pour window away from CH1N. The last is benign only for this scoped
  guard, not a blanket approval of arbitrary plane edits elsewhere.

These are **seven added native cases**, not an exhaustive mutation score or
physical experiments. The focused nine-case run also includes the two existing
CH1N cases; do not add it again to the complete suite. The all-net cut test now
cuts the new exposed CH1N trunk rather than an obsolete UUID; its native
connectivity expectation is unchanged.

## Execution, review and next task

Fresh source-capture run 36701686057 checked out exact main779b8efa from GitHub.
The clean baseline ordinary+schematic gate passed with 1,091 ordinary tests,
14 subtests, 145 native KiCad cases and the 22 console subset; branch coverage
86.06%, existing 71% floor unchanged. That baseline command did not request all
98 native/integration cases or an S3 target build. Read the repair PR's live
final-head results and independent review for subsequent acceptance; neither
this document nor a queued workflow is a pass.

Reproduction uses the existing locked commands:

```sh
uv sync --locked --all-extras
uv run --locked --all-extras python -m pytest -q tests/test_pcb_placement.py -k ch1n
uv run --locked --all-extras python -m tools.check --native --schematic
```

The engineering basis remains the source-bound PR65 input review. TI SCAA082A,
sections 1.4, 1.6 and 2.2/2.5, provides general coupling/reference/slot guidance:
https://www.ti.com/lit/an/scaa082a/scaa082a.pdf . Relevant page images were
inspected. It addresses high-speed layout and is not a quantitative low-frequency
EEG crosstalk criterion or manufacturer millimetre limit for this input. KiCad9
native shape/refill/DRC is used for geometry and connectivity, not field extraction.

**Next: dispose of the remaining nine upstream input/supply overlaps together**,
choosing one bounded combined repair or an explicit stackup/bench-test disposition
rather than endless single-crossing iterations. The routes involved are CH3P,
CH3N and CH4N against CH2N/AVDD; no filtered-INn branch remains among these nine.
Then advance the finite stackup/component/mechanical/interface decisions in
#45/#48. The 4.5-mm DNP-branch imbalance and other source/cable/parasite assumptions
remain separate characterization issues. No purchasing, fabrication, powered
connection or body-use authorization is granted.

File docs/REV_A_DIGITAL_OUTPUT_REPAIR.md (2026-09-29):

# MISO/DRDY output corridor repair

## Scope and identity

This repairs the exact authored PCB reviewed in PR #63, main
`f834221a092f78dee4191305a3c3a8a03def0283`, not the parking-grid importer.
See `checkpoints/20260930_digital_output_repair.json` for source identities,
coordinates, native item UUIDs, lengths and scoped reference-policy results.
The board SHA256 after this repair is
`232b7c68a63ae13aebcf71f8c0b1f210421c30452a1afc7b7c86dc1c118b23a3`.
The live repair branch is `fix/digital-output-corridor`; inspect its PR/checks
until merged, then continue from main. This document does not anticipate a
successful final-head CI or review that has not yet happened.

## Actual copper change

Both long output spans move from B.Cu to F.Cu. Short In2.Cu escapes remain
beside U1; F and In2 face the same continuous In1 ground conductor. The long
F routes are therefore separated from routed In2 copper by ground, unlike the
six unshielded B/In2 projected crossings recorded in the preceding review.
There is no B.Cu track on either output after this repair. This does not imply
zero coupling, controlled impedance, optimal return paths or measured timing.

An all-front path was blocked by existing front fanout, including CLKSEL.
Rather than move unrelated signals, each output uses two through vias and a
bounded local In2 escape. These are physical F-B vias connecting F/In2 tracks;
the unused barrel portion is not modelled. The original MISO source via stays
byte-identical. The former shared MISO/DRDY source clearance opening is gone:
a freshly refilled and unfractured native plane reports four distinct openings
for the four output vias, not one merged pair. This is a local fill observation,
not a guarantee of return impedance. Other SCLK/CS and CLK/START groups remain
unchanged review items. No ground split or blanket stitching rule was added.

| Output | Before F / In2 / B, mm | After F / In2 / B, mm | Vias before / after |
|---|---|---|---|
| MISO | 5.180 / 0 / 32.565 | 28.474 / 7.268 / 0 | 1 / 2 |
| DRDY | 20.824 / 0 / 15.675 | 36.257 / 7.875 / 0 | 2 / 2 |

These sums include every authored segment on the net, including any prior
branch/overlap; they are not shortest conductive itineraries and exclude barrel
and pad spreading. Total DRDY trace grows from36.499 to44.132mm; do not call
that a length/timing improvement. MISO changes37.745 to35.742mm. The two long
parallel front runs have0.45mm centre separation (0.30mm copper-edge gap) where
they run together. Neither that gap nor the longer DRDY path is a qualified
crosstalk or delay specification; edge rates, loads, harness and dielectric
stackup still need release/bench review. The change removes the specific
unshielded layer arrangement without claiming that every metric improves.

All68 footprint forms and all245 pad positions remain unchanged. Exactly20 old
output segments and two old output vias are removed;23 segments and three vias
are added. All680 retained track/via forms and every other non-zone board form
remain byte-identical. Totals are584segments/122vias. The sole GND zone source
settings are unchanged; only native filled copper is updated. No signal tracks
were added to In1. Tracks remain0.15mm, new vias0.60/0.30mm. No schematic, BOM,
firmware, model, dependency, clearance/severity/exclusion or approval change.

## Test-first boundary and controls

`c33d578` preserves two actual native failures on the original board: MISO and
DRDY violate the new local layer policy while canonical DRC remains0/0/0.
The native guard is in the already-snapshotted `tests/test_pcb_placement.py`.
It requires F-only long spans, at most two output vias, at most10mm of In2 in
the ADC-side rectangle, and a single filled In1 GND region. Those bounds are
local design decisions, not manufacturer frequency/noise limits. The
rectangle test uses endpoints only for straight In2 tracks; non-straight In2
tracks are now explicitly unsupported and rejected, not silently bounded by
their endpoints.

It also subtracts the actual native filled ground polygon from each output's
**full trace-width projection**, using integer polygon Booleans, not sparse
centreline probes. Only that output's own through-pad/via clearance shapes are
exempt. Their margin is the actual zone-local0.25mm plus25um for polygon
approximation (native shape error5um); it is not a general reference-gap
allowance. Other-net voids and added plane windows are not exempted. GND pads
and tracks outside filled copper are not added to the reference mask, so the
check can conservatively reject copper that needs explicit review.

The initial nine new native cases passed after repair: two canonical guards, two connected
wrong-layer copies, one connected reference-window copy, and four benign
reversal/subdivision copies. Each modified board is independently refilled
and DRC checked. The wrong-layer copies move each short escape to B without
breaking connectivity. A small pour-only keepout beneath both long front runs
leaves one connected ground region and normal DRC0/0/0, yet both full-width
reference checks fail. Benign edits preserve acceptance. Existing MISO/DRDY
cut-track probes now target the new exposed trunks; the test expectation is
unchanged. The initial nine cases are part of the full native suite, not added to
its total again. No exhaustive mutation score or physical experiment is claimed.

Development found and corrected native clearance collisions, an initially
wrong assumption about zone clearance, and a mutation-probe bug: native vector
getters must be copied before reversing track endpoints. Actual clearance was
read, not relaxed; test expectations were not weakened to accept zero-length
or colliding tracks. Intermediate failed/time-limited runs are not passes.

## Independent review correction: curved-escape loophole

Codex finding4139341193 on8bde876 identified that endpoints do not bound a
curved In2 track. Test-only21f97c9 reproduced the actual native failure: a DRDY
arc bows to y=36.8mm while both endpoints remain at y=36.4mm, inside the local
rectangle. The whole In2 route is8.292mm, ordinary DRC is0/0/0, full-width
reference is intact, and the old guard incorrectly accepts it.

Fix1c208f6 makes `inner_tracks_straight` an explicit gate field. Non-straight
In2 geometry is rejected until separately designed/reviewed support exists;
this is not a claim to test an arc's complete centreline bounds. Both canonical
outputs and the new native arc regression then passed. The final addition is
ten native cases total (initial nine plus this arc), not ten more after nine.
The copper is unchanged by this review fix. No length/clearance/error margin
was enlarged to pass the arc.

## Verification and next task

Fresh KiCad9.0.2 refill/DRC on the candidate has0parity/0other/0unconnected and
exit0. The complete baseline gate passed on exactf834221a. The initial focused
nine-case result and three-case review retest are separate from final-head
verification: read the
live PR's final local/hosted reports and independent review before merge.
One local8bde876 combined gate reached the existing300s native-suite timeout;
it is retained as a failed run, not a pass. Its hosted five-job gate completed
successfully, but that earlier head does not validate the later review fix.
No project process timeout or engineering threshold was relaxed.
A clean source identity, green software tests and native DRC are not professional
or physical electrical qualification. Normal final gates include the existing
AVDD1/VCAP, all-net cut and schematic-parity controls; do not substitute only the
new output tests for them.

After this scoped repair is reviewed/merged, perform the input P/N geometry and
coupling review, separately connector-to-resistor and resistor-to-ADC. Preserve
the AVDD1 repair and its documented neighboring-path tradeoffs. Keep#45/#48 open:
stackup/mechanical/assembly, capacitor lifecycle/effective-C, real console/rail-loss
behaviour and delivered budget remain unresolved. No purchase, fabrication,
powered connection or body use is authorized.

The engineering basis remains `REV_A_DIGITAL_RETURN_REVIEW.md` and its primary
TI sources. This repair adds native geometric evidence, not new vendor claims.

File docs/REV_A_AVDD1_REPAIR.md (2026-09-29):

# AVDD1 local bypass repair: native draft, not electrical qualification

PR #62 follows the geometry finding in `REV_A_POWER_RETURN_REVIEW.md`.
Before source: `1e86c049c46b52b3f1889f6bef7941763f965f79`.
First published repair/test head: `a19bfc4514d7923aba33e8ee5c1d0009e3c5e931`.
Board after SHA256: `611218bae6559fb2488309fc80eee20ce2d6b5855977d52d600f947099179b43`.
Read the live PR for final exact-head CI/review and merge state. This document
and its geometry record do not certify a later edit.

## What changed

C16 (1 uF) and C27 (100 nF) now sit immediately above U1's AVDD1/AVSS1
pin pair. U1.54 reaches both positive pads on front copper; U1.53 reaches
both negative pads on front copper. Shared AVDD feed and GND plane entry
are beyond the capacitor cluster, not a substitute for these local paths.
C9, C24 and C14 also move to make room. All five remain front-side; no
part is under U1. No ferrite, split ground, new part or schematic net is added.

Native comparison of all 68 footprints and 245 pads found identical field
texts, values, footprint IDs, attributes/layers and relative pad definitions
(including net, drill, size, shape, pin function/type and orientation). Only
those five footprint positions/orientations change. The other 63 footprint
forms remain byte-identical. No signal tracks are added to In1. The board
now has 581 segments and 121 vias; new vias retain 0.60/0.30 mm geometry.
BOM, schematic, firmware, models, dependencies and approval flags are unchanged.

## Measured geometry and tradeoffs

Lengths below are specified trace-centre itineraries, not the shortest
conductive distance, pad spreading, via-barrel length, loop inductance, or
noise measurements. The JSON record lists the exact after-route UUIDs; the
previous review retains its before-route portions. Do not compare the old
9.325 mm GND-plane-entry separation with a new trace length as if they were
the same metric.

| Path | Before trace mm / vias | After trace mm / vias |
|---|---:|---:|
| U1.54 to C16.1 | 11.936 / 2 | 2.617 / 0 |
| U1.54 to C27.1 | 11.036 / 2 | 4.217 / 0 |
| U1.53 to C16.2 | Via/plane-dependent, no direct front path | 3.726 / 0 |
| U1.53 to C27.2 | Via/plane-dependent, no direct front path | 5.326 / 0 |
| U1.55 to C9.1, VCAP3 | 2.533 / 0 | 2.816 / 0 |
| U1.55 to C24.1, VCAP3 HF | 4.033 / 0 | 6.016 / 0 |
| U1.56 to designated C14.1 | 1.913 / 0 | 6.713 / 0 |
| U1.56 to shared C15.1 | Not tabulated here | 3.663 / 0 |

**Not every neighboring path improved.** C9 remains near its pin and both
VCAP3 paths stay front-only, but C24's path is about 1.98 mm longer. C14's
path is substantially longer; the nearer shared C15 path is explicitly an
alternative, not a changed capacitor ContractRef. U1.59's existing C15 path
and the DVDD C18 route are unchanged. Retain these tradeoffs in whole-board
supply/noise review; this repair does not establish their physical performance.

The pre-repair VCAP3 figures were summed from the original front-route
portions: U1.55 (48.75,31.3375) through its native bends to the C9 pad centre
(50,29.425), then the extra 1.5 mm to C24 (51.5,29.425). Both source boards
remain in Git. Use the explicit after UUIDs in the companion JSON to audit
these numbers rather than treating a printed rounded number as a constraint.

## Tests before repair, then connected-but-wrong faults

Test-only `cb11bb7a` produced four intended native failures for missing local
AVDD1 positive/return paths; both VCAP3 guards passed. `b2e11969` repairs copper.
Test-only `470ba37d` then exposed two accepted early plane joins despite intact
local paths. `a19bfc45` fixes that guard using native KiCad item types: connectivity
returns vias as generic track proxies, so Python isinstance is not sufficient.

The initial eleven added native cases passed locally: six bounded front-path checks, two
indirect reconnections, two additional upstream plane joins, and one benign
track subdivision/reversal. Each fault copy is freshly refilled and checked.
The four harmful controls still have zero ordinary DRC/parity/airwires; the
local guard rejects them. A globally connected supply is therefore not accepted
as evidence that the required local bypass connection remains present.

The test limits are project geometric guardrails chosen before repair, not TI
maximum-length or noise specifications. Native whole-contacted-item distance
can vary with subdivision near a pad; the benign control tests acceptance and
terminal identity, not an artificial invariant floating-point length. The
pre-bypass walk uses each requested capacitor's native pad contacts as its
boundary, not the first member of the bank. It also follows intermediate pad
contacts and side branches that do not touch the requested target pad. It is
not an exact geometric cut for arbitrary overlapping or long boundary tracks;
such future geometry still requires direct review.

The canonical board and native fault tests remain in `tests/test_pcb_placement.py`.
The authored board keeps its fresh zone last so the existing removed-cache test
does not accidentally discard later tracks. No rule/severity/exclusion/threshold
was relaxed. Reproduce with the existing pinned environment:

```sh
uv sync --locked --all-extras
uv run --locked python -m tools.check --native --schematic
```

## Review continuation: guard the whole bank, not only the first capacitor

Codex review comment `4137830251` on exact head `189a6e606b376224735ae05bc9c820fe74bcbed0`
identified a real test gap: a plane connection added between C16 and C27 was
missed because the walk stopped at C16. This is a checker defect, not an
observation that the canonical board already has that unwanted connection.

Test-only `13c4ec2a89464010966e4778628c46240caf0eeb` reproduced **two actual native failures**: one new
AVDD via connected to the existing In2 supply feed and one GND via connected
to the filled In1 plane, each halfway between the capacitor pads. Fresh native
refill/DRC remained 0/0/0, both bounded direct paths remained present, and the
old guard incorrectly reported no pre-entry exit for C27.

Fix `16fe27809f6a96d42078580929672ac1c2f70995` checks each capacitor's boundary
separately. Other capacitors in the same bank are allowed contacts, not stopping
points. The new controls identify the join as downstream of C16 but upstream
of C27. The three benign controls split/reverse the device entry, positive
inter-capacitor and return inter-capacitor tracks; all remain accepted. All
**15 focused native cases** passed locally after the correction. The two
indirect reconnections, two pre-bank joins and two inter-capacitor joins are
six scoped native fault controls, not exhaustive copper/physical fault coverage.
No geometry limit, board byte, circuit value or approval flag changed here.

A further native review probe found that track-only traversal could stop at
C16 when two track ends contact its pad but no longer touch each other. Red
`f805fe04c28be73de18a444d85bb6ef01d82eb1a` shortened each inter-capacitor track
by 0.35 mm inside the C16 pad, on positive and return sides separately. Two
benign cases passed, but adding the known mid-bank entry produced two missed
faults despite native DRC 0/0/0 and intact local paths. Fix
`86b45e6d05810cc83250145d07e7862e17d1d476` also traverses the native contacts of
an intermediate bank pad, without crossing the capacitor dielectric or changing
the requested boundary. All **19 focused native cases** then passed: six
canonical/local/VCAP guards, eight harmful controls, and five benign controls.
The earlier 15-case result remains a dated preceding checkpoint, not the final
case count. This extension changes no authored copper or geometric thresholds.

Codex's renewed review `4138094514` on `dd7511bb` identified another boundary
case: a front-layer spur off the target-contacting track can reach a plane via
without that via directly contacting the boundary track. Red
`808107704d0856ee3929f3f4266ec7a09378d48f` reproduced two missed pre-capacitor
spurs and accepted two post-bank feed controls; all four modified boards were
freshly refilled and DRC-clean. Fix
`e14d52e3813573800f47832b8b54dbf174a07b7d` excludes only outgoing tracks that
also contact the requested pad; non-boundary side branches remain traversable.
This retains the post-bank feed as an accepted boundary rather than declaring
all supply vias erroneous. **23 focused native cases passed**: six local/VCAP
guards, ten harmful controls and seven benign controls. No canonical copper,
threshold, dependency or approval flag changed. This is a scoped contact-graph
guard, not a field solver or an exhaustive geometrical proof.

The live PR, not a previous chat candidate, is the continuation source. The
chat-delivered local `1689234ebb49b6f8c046bff0c785753669c2a0e2` has tree
`ee6dfa9eb393e54c11b9473b6aa7bbf40416dc55` and board SHA256
`e73e26bc4c50be3e81cfc691217cac238d2e5890b6b0e9f2ab90d4c7b79876c2`.
It is a **different, unmerged variant**, not the ancestor or tested board of
PR #62. Its archive and all 2,317 payload hashes were verified and preserved
separately in this continuation, not applied over the live PR. Its measurements,
126 KiCad cases and 1,092 ordinary tests must not be reused as this PR's evidence.
Continuing the already-published PR avoids overwriting work and addresses its
actual outstanding review. No old chat archive is needed for subsequent work
on this published source. See `checkpoints/20260929_avdd1_review_continuation.json`.

## Recovery and evidence boundary

The preceding failed turn left working tool artifacts but an incomplete source
transfer, not a recoverable published repair. This continuation recovered the
published main source and native tools from GitHub, reproduced the failures,
and published its four actual commits. Transfer run36622822760 verified the
14,068-byte Git bundle and a separate fresh GitHub checkout. Transfer code and
runtime binaries are not project dependencies and are not in the product tree.

An initial full local gate stopped because the transported ngspice runtime
lacked its stock initialization file. The exact distribution spinit was restored
outside project source; no model or expected result was edited to hide it.
Use the PR's final execution report for completed gate counts and outcomes.

Primary basis: TI ADS1299 SBAS499C, pp6,70,72, and Brian Pisani's TI E2E reply
recommend local AVDD1/AVSS1 bypass before the planes/pours, while recognizing
layout tradeoffs require performance judgment. Neither source gives the test's
millimetre limits or approves this board.
- https://www.ti.com/lit/ds/symlink/ads1299.pdf
- https://e2e.ti.com/support/data-converters-group/data-converters/f/data-converters-forum/462184/ads1299-98-does-avdd1-avss1-really-produce-significant-noise

Next: digital reference/layer-transition review on the live authored board,
then input P/N geometry/coupling. Keep #45/#48 open, including whole-board
supply tradeoffs, stackup, mechanics/assembly, component lifecycle/effective C,
and actual console/interface rail-loss behavior. No fabrication, purchasing,
power-up or body-use authorization; native CAD and source review are not
physical experiments or independent professional electrical qualification.

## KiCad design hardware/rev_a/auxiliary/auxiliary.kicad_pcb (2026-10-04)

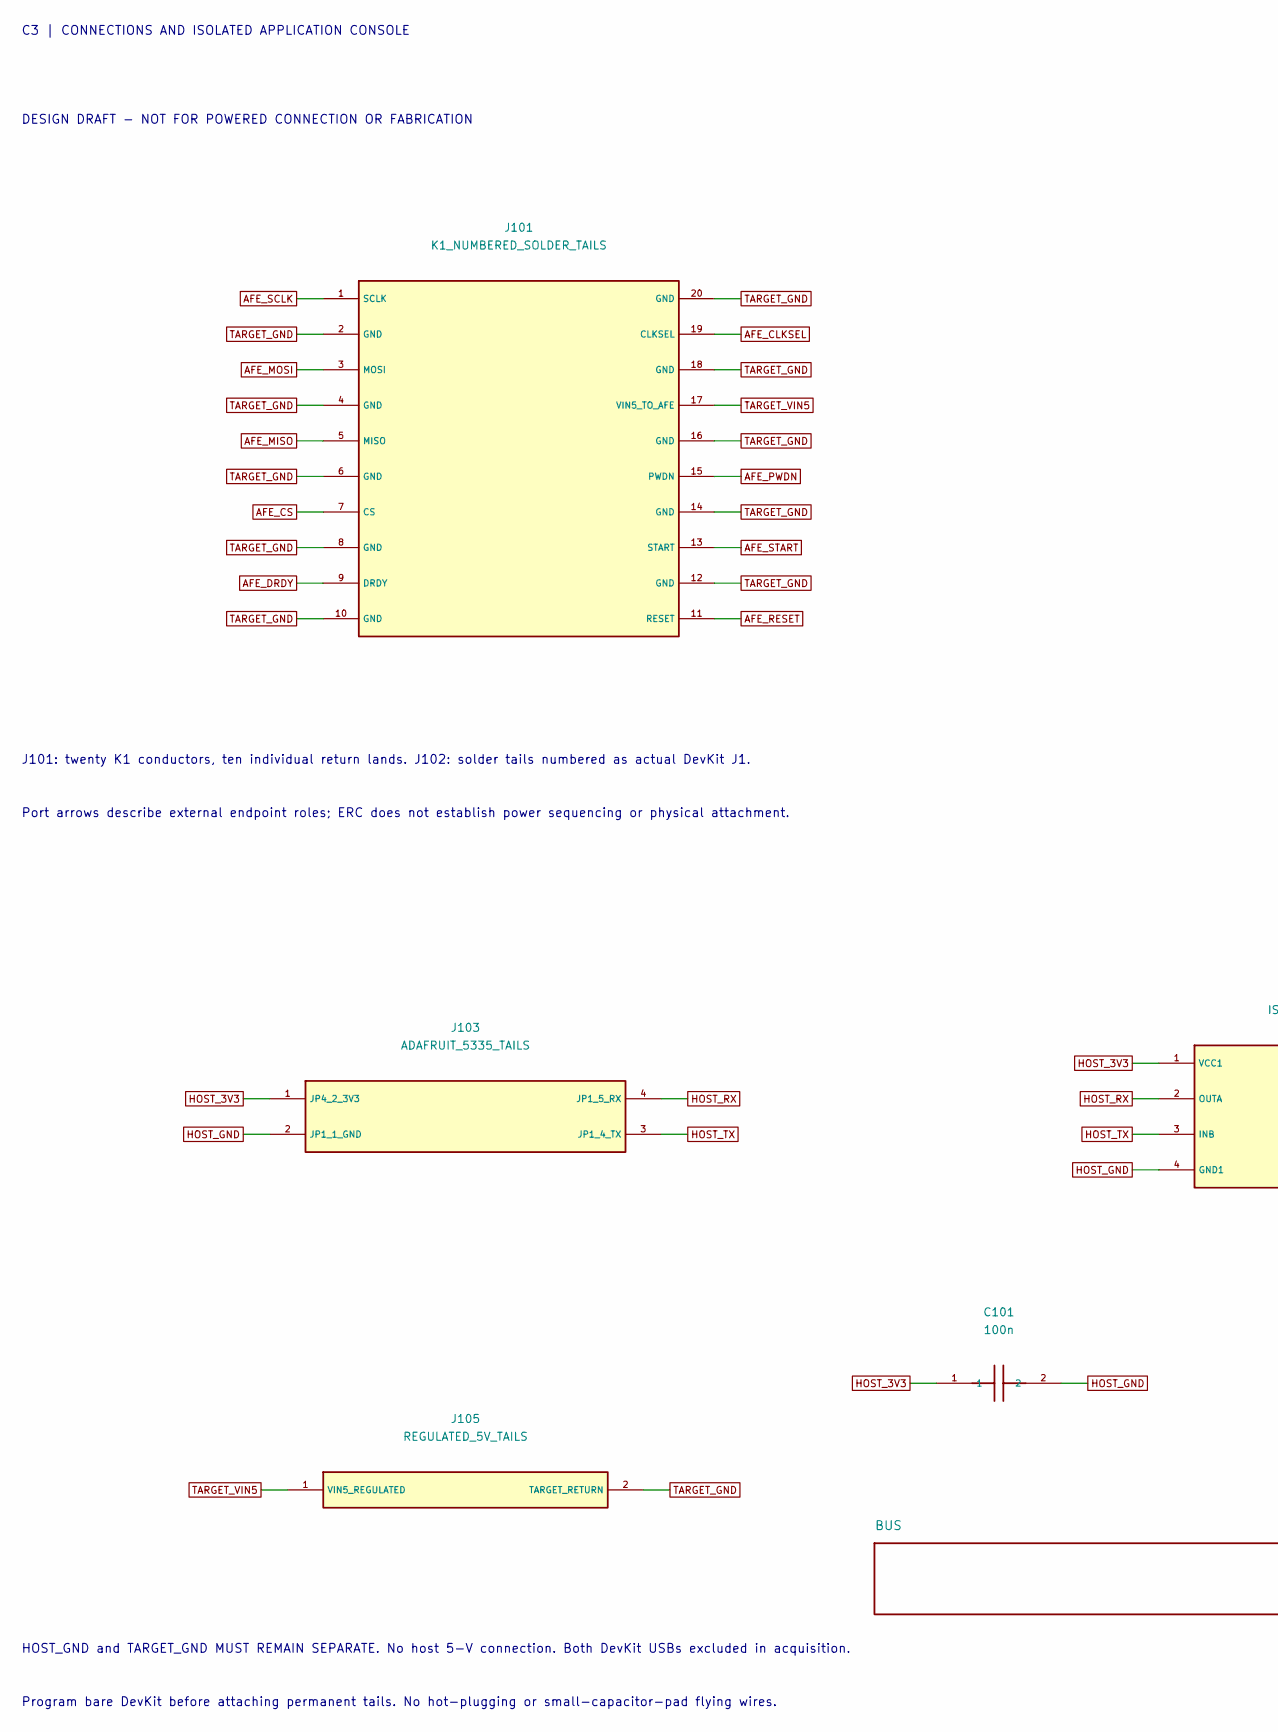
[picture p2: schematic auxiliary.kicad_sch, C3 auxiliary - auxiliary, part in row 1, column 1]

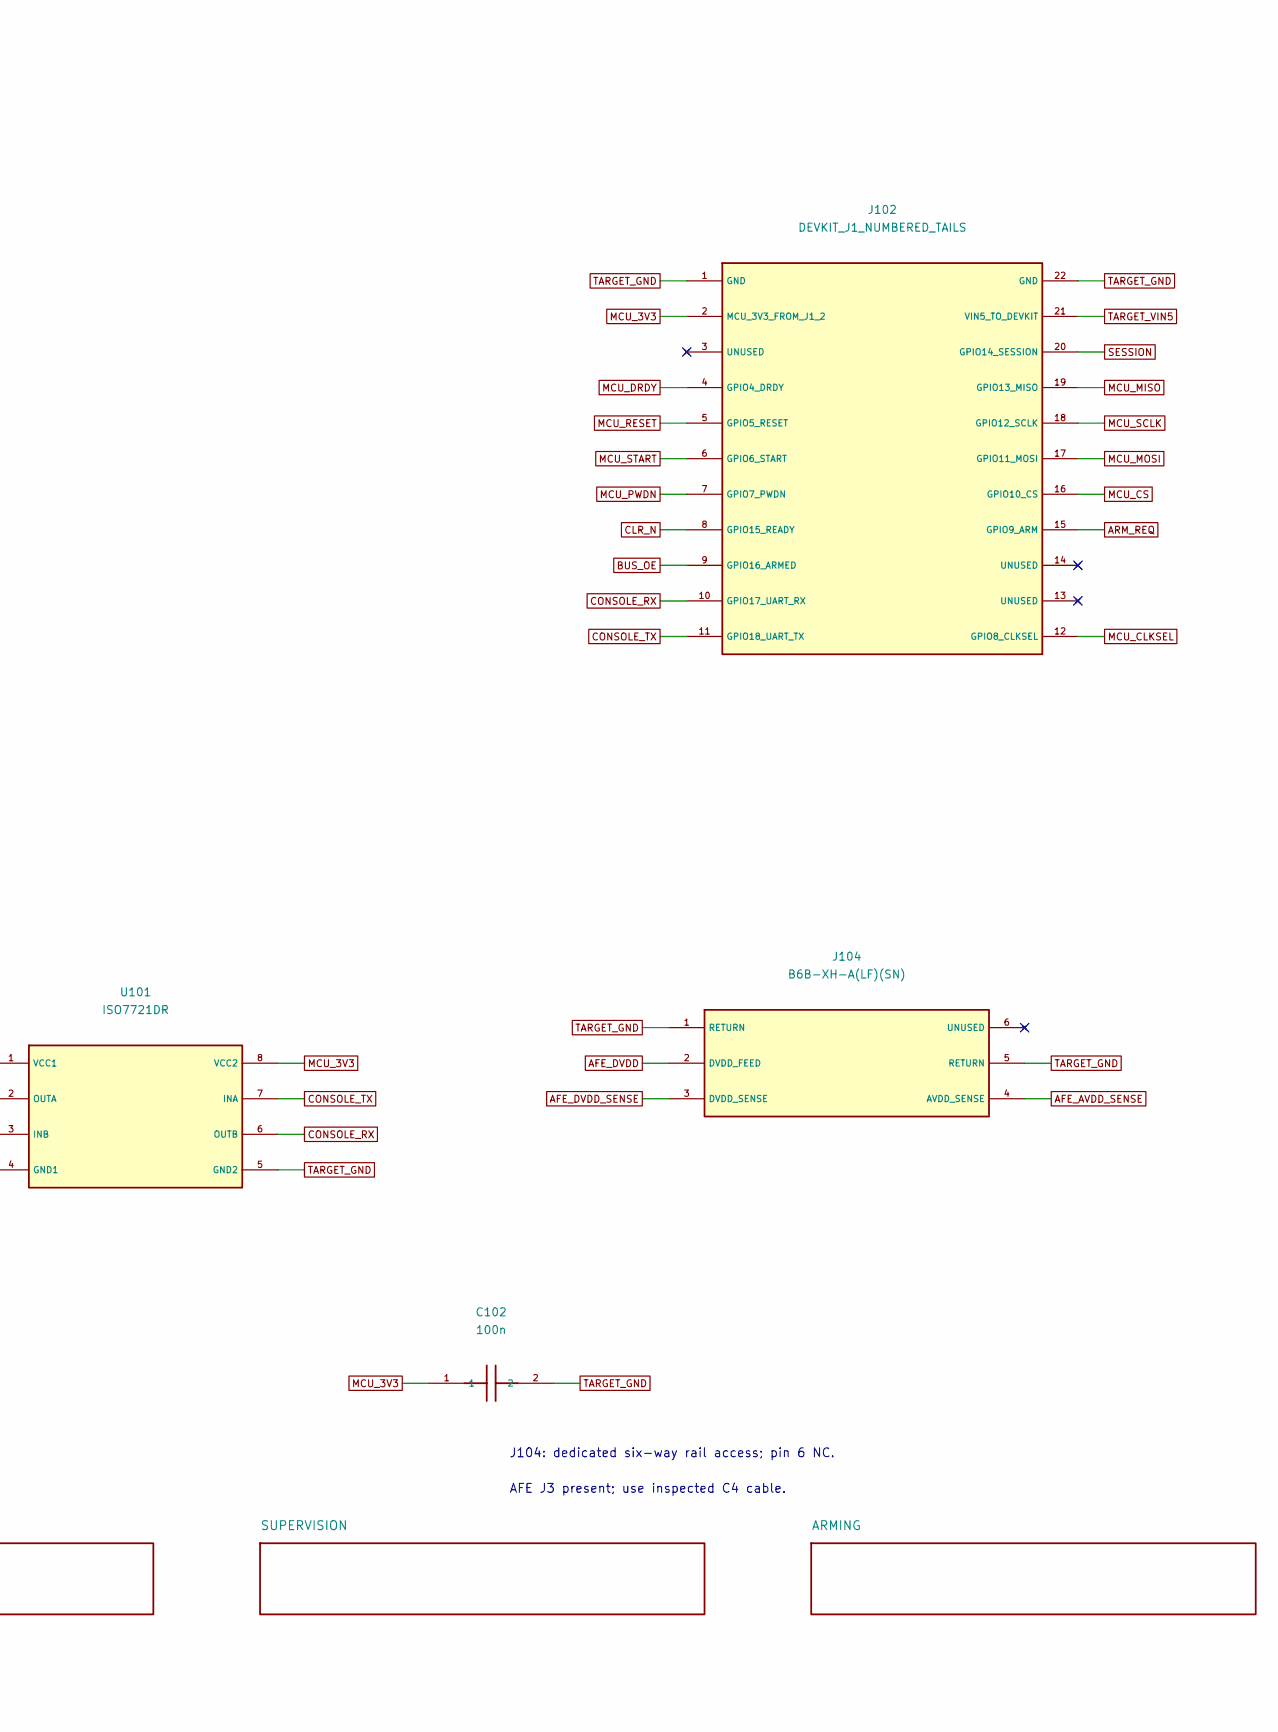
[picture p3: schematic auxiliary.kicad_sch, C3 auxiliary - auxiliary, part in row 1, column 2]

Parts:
C101, C102: 100n; C_0603_1608Metric; MPN C0603C104K5RACTU
J101: K1_NUMBERED_SOLDER_TAILS; SolderTails_20; MPN PCB_LANDINGS_ONLY
J102: DEVKIT_J1_NUMBERED_TAILS; SolderTails_22; MPN PCB_LANDINGS_ONLY
J103: ADAFRUIT_5335_TAILS; SolderTails_4; MPN PCB_LANDINGS_ONLY
J104: B6B-XH-A(LF)(SN); JST_XH_B6B-XH-A_1x06_P2.50mm_Vertical; MPN B6B-XH-A(LF)(SN)
J105: REGULATED_5V_TAILS; SolderTails_2; MPN PCB_LANDINGS_ONLY
U101: ISO7721DR; SOIC-8_3.9x4.9mm_P1.27mm; MPN ISO7721DR

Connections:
AFE_AVDD_SENSE: J104.4 (AVDD_SENSE); also elsewhere on the board
AFE_CLKSEL: J101.19 (CLKSEL); also elsewhere on the board
AFE_CS: J101.7 (CS); also elsewhere on the board
AFE_DRDY: J101.9 (DRDY); also elsewhere on the board
AFE_DVDD: J104.2 (DVDD_FEED); also elsewhere on the board
AFE_DVDD_SENSE: J104.3 (DVDD_SENSE); also elsewhere on the board
AFE_MISO: J101.5 (MISO); also elsewhere on the board
AFE_MOSI: J101.3 (MOSI); also elsewhere on the board
AFE_PWDN: J101.15 (PWDN); also elsewhere on the board
AFE_RESET: J101.11 (RESET); also elsewhere on the board
AFE_SCLK: J101.1 (SCLK); also elsewhere on the board
AFE_START: J101.13 (START); also elsewhere on the board
ARM_REQ: J102.15 (GPIO9_ARM); also elsewhere on the board
BUS_OE: J102.9 (GPIO16_ARMED); also elsewhere on the board
CLR_N: J102.8 (GPIO15_READY); also elsewhere on the board
CONSOLE_RX: J102.10 (GPIO17_UART_RX), U101.6 (OUTB)
CONSOLE_TX: J102.11 (GPIO18_UART_TX), U101.7 (INA)
HOST_3V3: C101.1, J103.1 (JP4_2_3V3), U101.1 (VCC1)
HOST_GND: C101.2, J103.2 (JP1_1_GND), U101.4 (GND1)
HOST_RX: J103.4 (JP1_5_RX), U101.2 (OUTA)
HOST_TX: J103.3 (JP1_4_TX), U101.3 (INB)
MCU_3V3: C102.1, J102.2 (MCU_3V3_FROM_J1_2), U101.8 (VCC2); also elsewhere on the board
MCU_CLKSEL: J102.12 (GPIO8_CLKSEL); also elsewhere on the board
MCU_CS: J102.16 (GPIO10_CS); also elsewhere on the board
MCU_DRDY: J102.4 (GPIO4_DRDY); also elsewhere on the board
MCU_MISO: J102.19 (GPIO13_MISO); also elsewhere on the board
MCU_MOSI: J102.17 (GPIO11_MOSI); also elsewhere on the board
MCU_PWDN: J102.7 (GPIO7_PWDN); also elsewhere on the board
MCU_RESET: J102.5 (GPIO5_RESET); also elsewhere on the board
MCU_SCLK: J102.18 (GPIO12_SCLK); also elsewhere on the board
MCU_START: J102.6 (GPIO6_START); also elsewhere on the board
SESSION: J102.20 (GPIO14_SESSION); also elsewhere on the board
TARGET_GND: C102.2, J101.2 (GND), J101.4 (GND), J101.6 (GND), J101.8 (GND), J101.10 (GND), J101.12 (GND), J101.14 (GND), J101.16 (GND), J101.18 (GND), J101.20 (GND), J102.1 (GND), J102.22 (GND), J104.1 (RETURN), J104.5 (RETURN), J105.2 (TARGET_RETURN), U101.5 (GND2); also elsewhere on the board
TARGET_VIN5: J101.17 (VIN5_TO_AFE), J102.21 (VIN5_TO_DEVKIT), J105.1 (VIN5_REGULATED); also elsewhere on the board

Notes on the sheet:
C3 | CONNECTIONS AND ISOLATED APPLICATION CONSOLE
DESIGN DRAFT - NOT FOR POWERED CONNECTION OR FABRICATION
J101: twenty K1 conductors, ten individual return lands. J102: solder tails numbered as actual DevKit J1.
Port arrows describe external endpoint roles; ERC does not establish power sequencing or physical attachment.
J104: dedicated six-way rail access; pin 6 NC.
AFE J3 present; use inspected C4 cable.
HOST_GND and TARGET_GND MUST REMAIN SEPARATE. No host 5-V connection. Both DevKit USBs excluded in acquisition.
Program bare DevKit before attaching permanent tails. No hot-plugging or small-capacitor-pad flying wires.

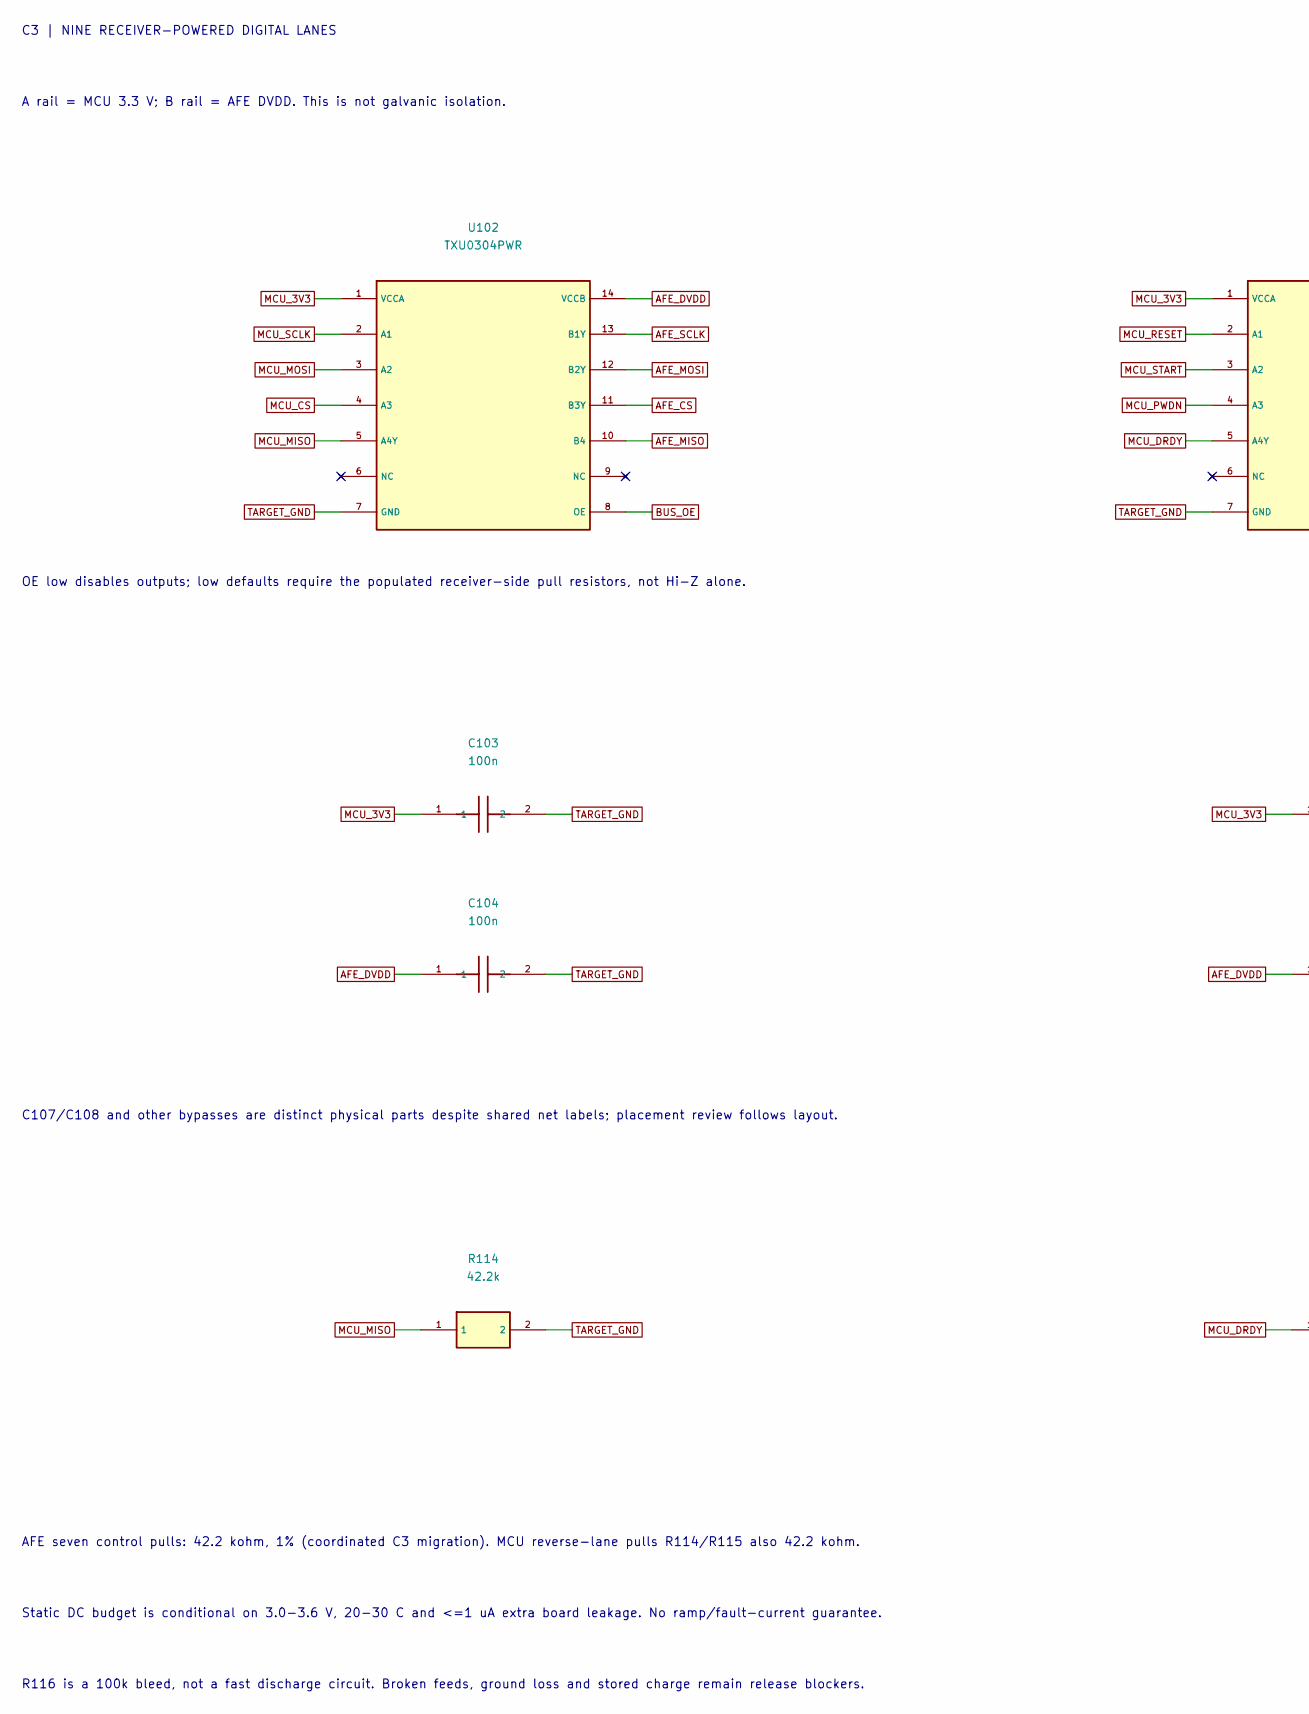
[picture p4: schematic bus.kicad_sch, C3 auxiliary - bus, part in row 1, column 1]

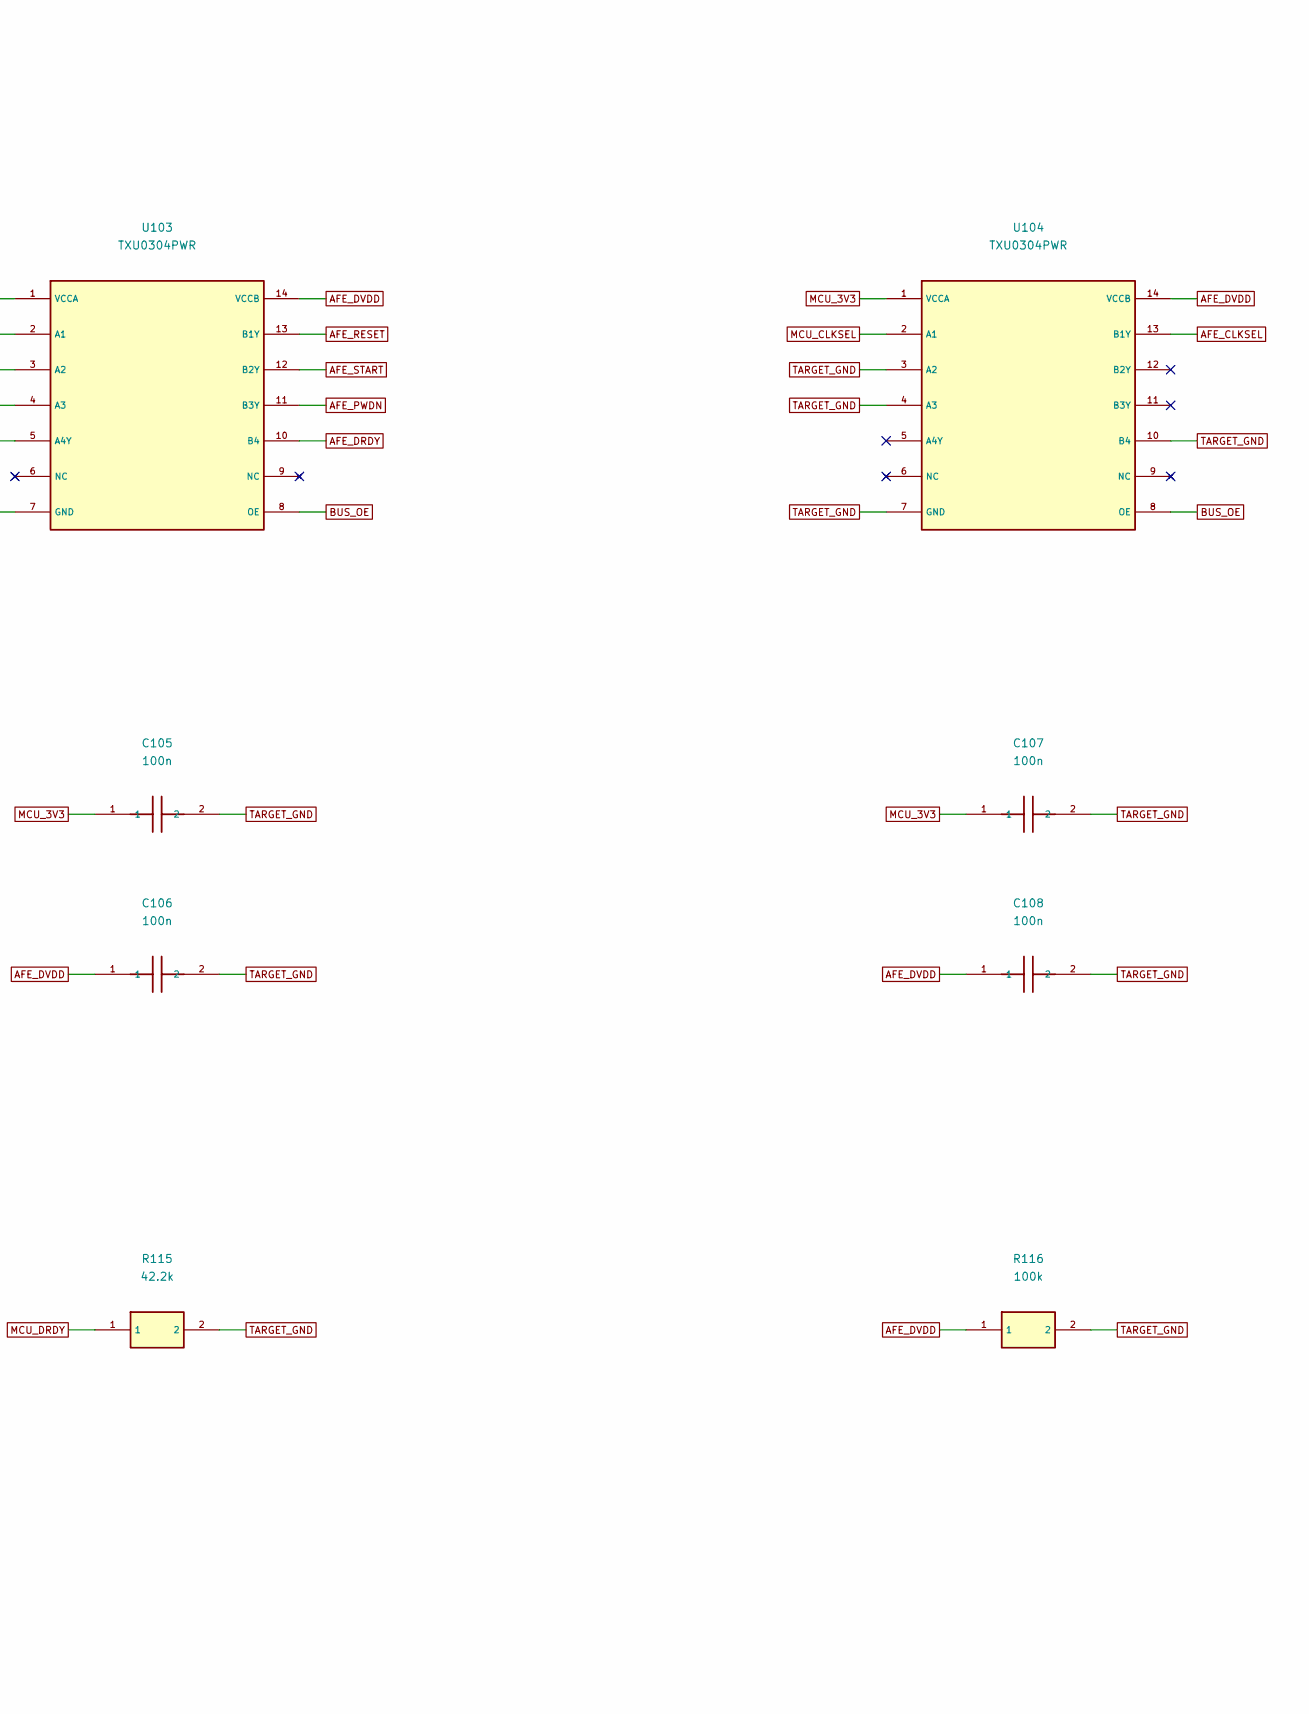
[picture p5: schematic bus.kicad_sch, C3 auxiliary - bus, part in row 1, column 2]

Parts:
C103, C104, C105, C106, C107, C108: 100n; C_0603_1608Metric; MPN C0603C104K5RACTU
R114, R115: 42.2k; R_0603_1608Metric; MPN RC0603FR-0742K2L
R116: 100k; R_0603_1608Metric; MPN RC0603FR-07100KL
U102, U103, U104: TXU0304PWR; TSSOP-14_4.4x5mm_P0.65mm; MPN TXU0304PWR

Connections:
AFE_CLKSEL: U104.13 (B1Y); also elsewhere on the board
AFE_CS: U102.11 (B3Y); also elsewhere on the board
AFE_DRDY: U103.10 (B4); also elsewhere on the board
AFE_DVDD: C104.1, C106.1, C108.1, R116.1, U102.14 (VCCB), U103.14 (VCCB), U104.14 (VCCB); also elsewhere on the board
AFE_MISO: U102.10 (B4); also elsewhere on the board
AFE_MOSI: U102.12 (B2Y); also elsewhere on the board
AFE_PWDN: U103.11 (B3Y); also elsewhere on the board
AFE_RESET: U103.13 (B1Y); also elsewhere on the board
AFE_SCLK: U102.13 (B1Y); also elsewhere on the board
AFE_START: U103.12 (B2Y); also elsewhere on the board
BUS_OE: U102.8 (OE), U103.8 (OE), U104.8 (OE); also elsewhere on the board
MCU_3V3: C103.1, C105.1, C107.1, U102.1 (VCCA), U103.1 (VCCA), U104.1 (VCCA); also elsewhere on the board
MCU_CLKSEL: U104.2 (A1); also elsewhere on the board
MCU_CS: U102.4 (A3); also elsewhere on the board
MCU_DRDY: R115.1, U103.5 (A4Y); also elsewhere on the board
MCU_MISO: R114.1, U102.5 (A4Y); also elsewhere on the board
MCU_MOSI: U102.3 (A2); also elsewhere on the board
MCU_PWDN: U103.4 (A3); also elsewhere on the board
MCU_RESET: U103.2 (A1); also elsewhere on the board
MCU_SCLK: U102.2 (A1); also elsewhere on the board
MCU_START: U103.3 (A2); also elsewhere on the board
TARGET_GND: C103.2, C104.2, C105.2, C106.2, C107.2, C108.2, R114.2, R115.2, R116.2, U102.7 (GND), U103.7 (GND), U104.3 (A2), U104.4 (A3), U104.7 (GND), U104.10 (B4); also elsewhere on the board

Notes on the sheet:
C3 | NINE RECEIVER-POWERED DIGITAL LANES
A rail = MCU 3.3 V; B rail = AFE DVDD. This is not galvanic isolation.
OE low disables outputs; low defaults require the populated receiver-side pull resistors, not Hi-Z alone.
C107/C108 and other bypasses are distinct physical parts despite shared net labels; placement review follows layout.
AFE seven control pulls: 42.2 kohm, 1% (coordinated C3 migration). MCU reverse-lane pulls R114/R115 also 42.2 kohm.
Static DC budget is conditional on 3.0-3.6 V, 20-30 C and <=1 uA extra board leakage. No ramp/fault-current guarantee.
R116 is a 100k bleed, not a fast discharge circuit. Broken feeds, ground loss and stored charge remain release blockers.

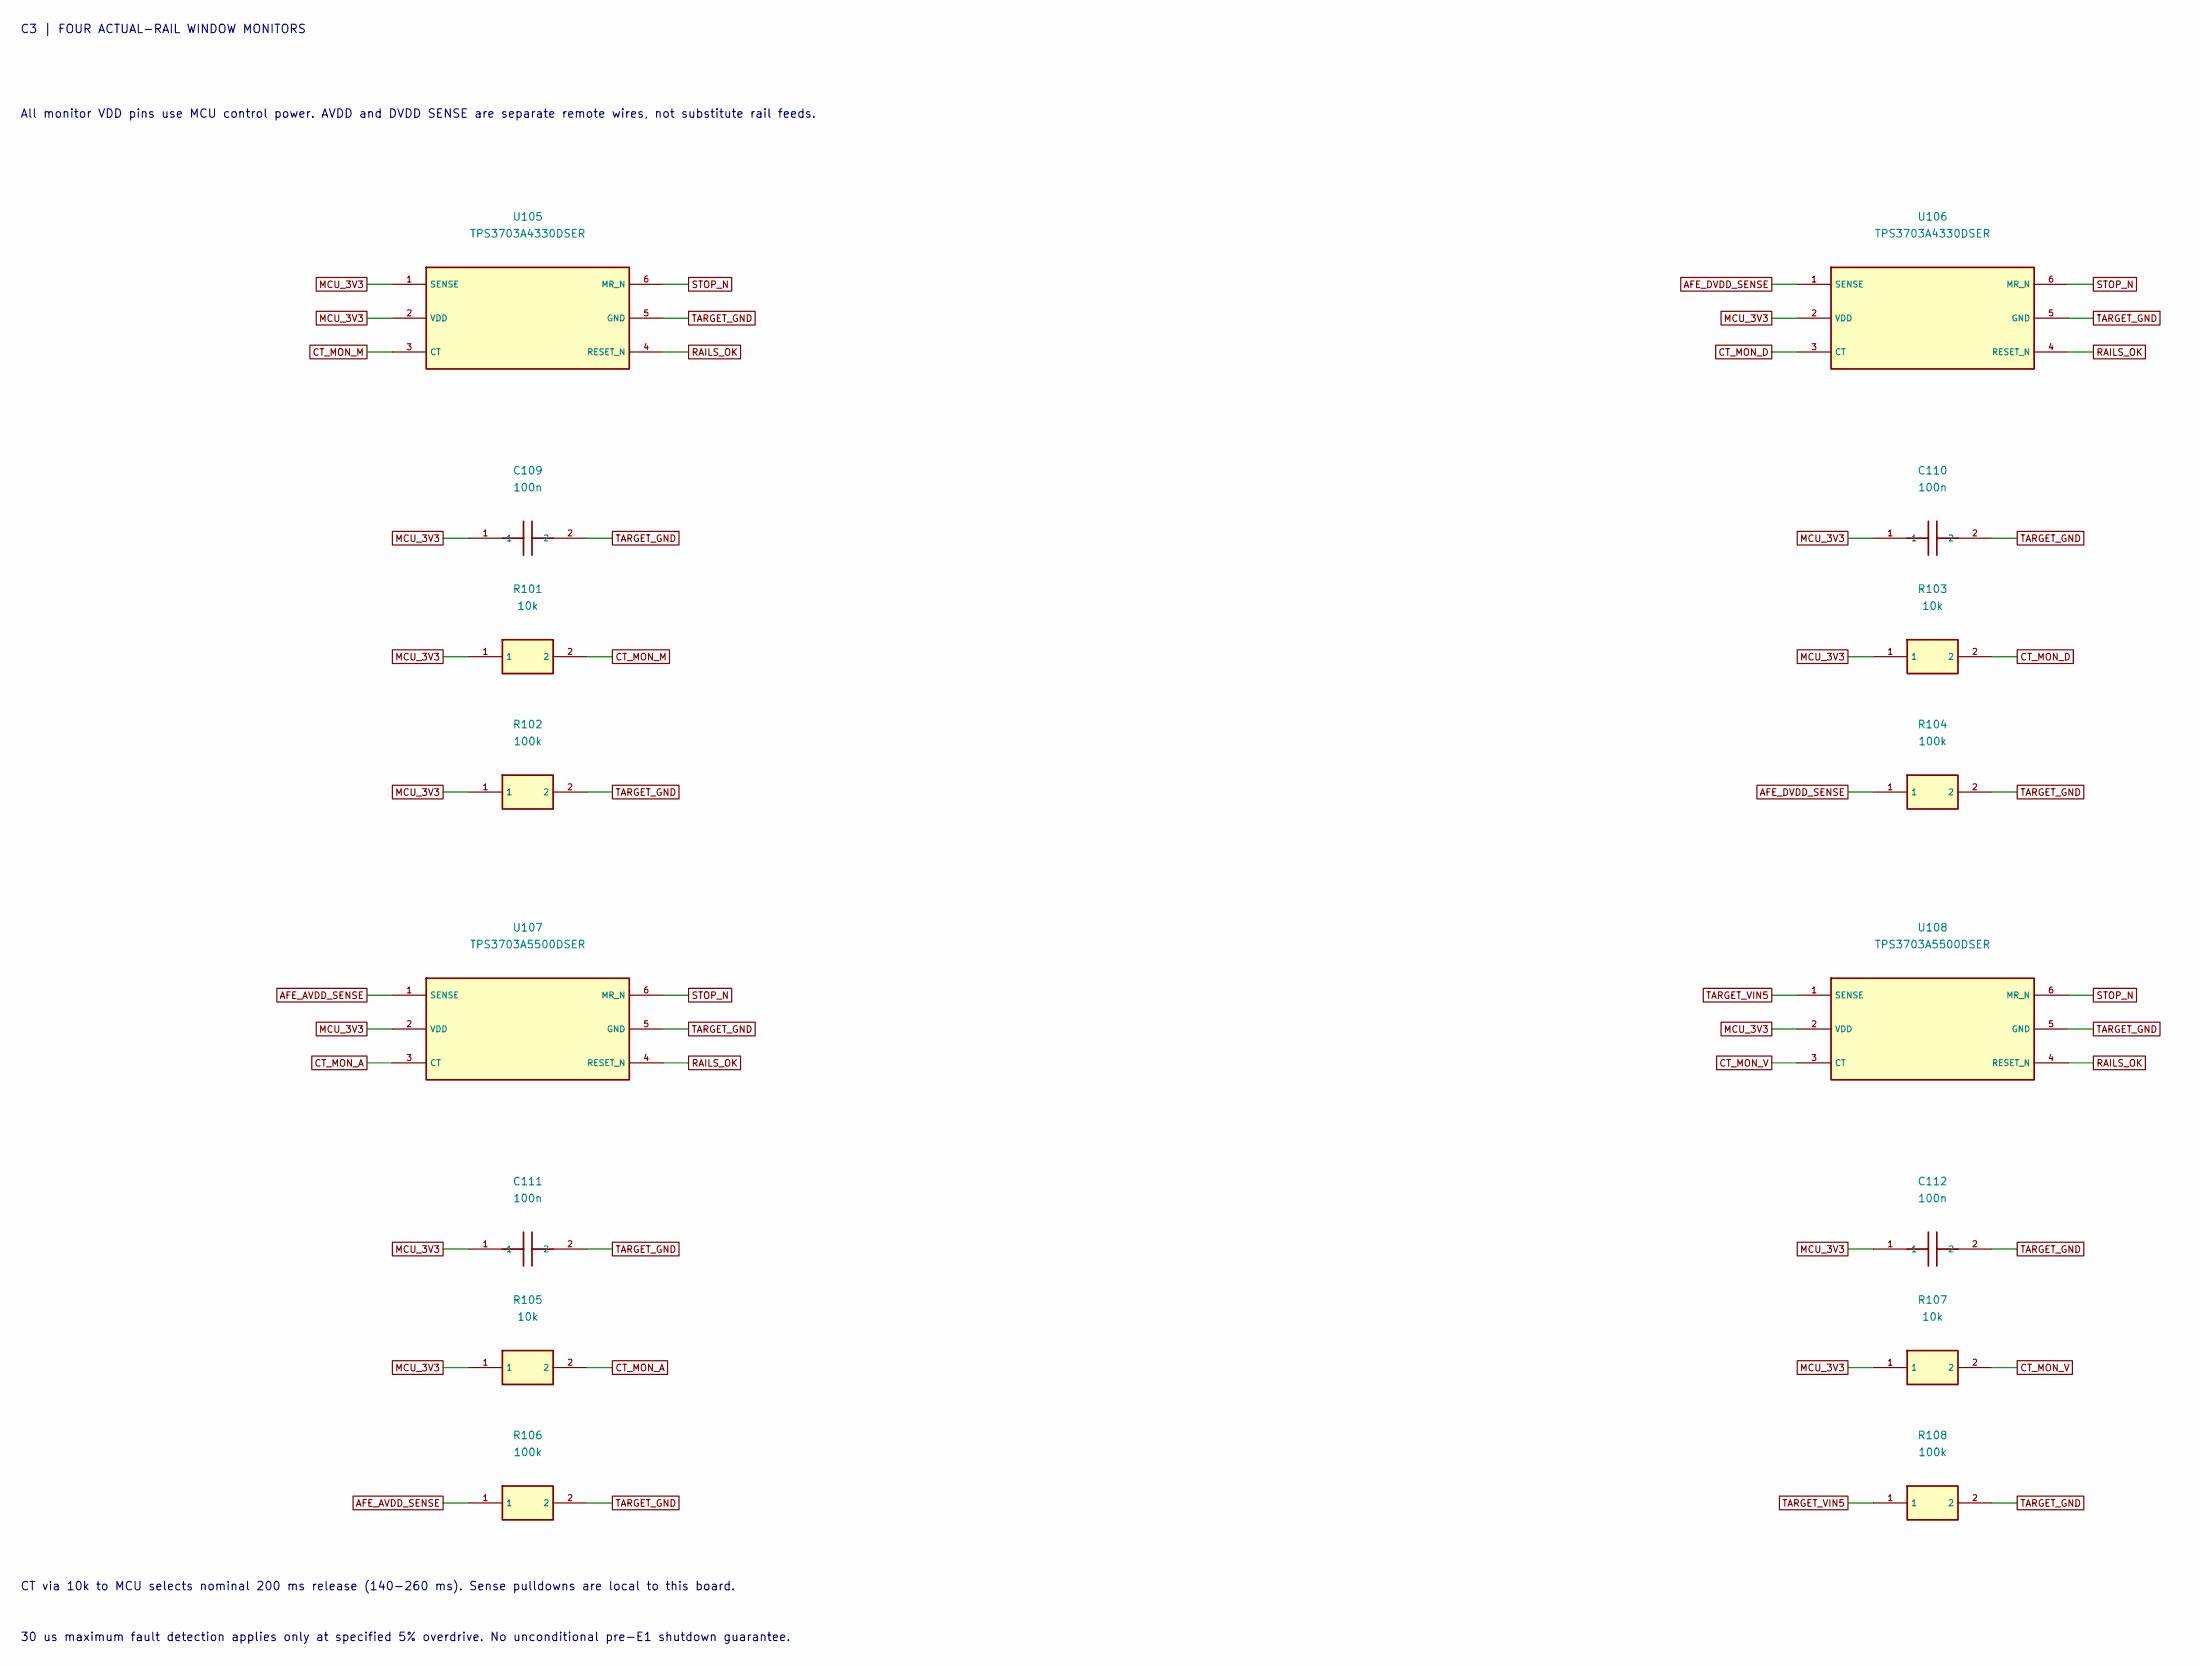
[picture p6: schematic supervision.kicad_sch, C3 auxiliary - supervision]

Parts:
C109, C110, C111, C112: 100n; C_0603_1608Metric; MPN C0603C104K5RACTU
R101, R103, R105, R107: 10k; R_0603_1608Metric; MPN RC0603FR-0710KL
R102, R104, R106, R108: 100k; R_0603_1608Metric; MPN RC0603FR-07100KL
U105, U106: TPS3703A4330DSER; WSON-6_1.5x1.5mm_P0.5mm; MPN TPS3703A4330DSER
U107, U108: TPS3703A5500DSER; WSON-6_1.5x1.5mm_P0.5mm; MPN TPS3703A5500DSER

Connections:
AFE_AVDD_SENSE: R106.1, U107.1 (SENSE); also elsewhere on the board
AFE_DVDD_SENSE: R104.1, U106.1 (SENSE); also elsewhere on the board
CT_MON_A: R105.2, U107.3 (CT)
CT_MON_D: R103.2, U106.3 (CT)
CT_MON_M: R101.2, U105.3 (CT)
CT_MON_V: R107.2, U108.3 (CT)
MCU_3V3: C109.1, C110.1, C111.1, C112.1, R101.1, R102.1, R103.1, R105.1, R107.1, U105.1 (SENSE), U105.2 (VDD), U106.2 (VDD), U107.2 (VDD), U108.2 (VDD); also elsewhere on the board
RAILS_OK: U105.4 (RESET_N), U106.4 (RESET_N), U107.4 (RESET_N), U108.4 (RESET_N); also elsewhere on the board
STOP_N: U105.6 (MR_N), U106.6 (MR_N), U107.6 (MR_N), U108.6 (MR_N); also elsewhere on the board
TARGET_GND: C109.2, C110.2, C111.2, C112.2, R102.2, R104.2, R106.2, R108.2, U105.5 (GND), U106.5 (GND), U107.5 (GND), U108.5 (GND); also elsewhere on the board
TARGET_VIN5: R108.1, U108.1 (SENSE); also elsewhere on the board

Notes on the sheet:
C3 | FOUR ACTUAL-RAIL WINDOW MONITORS
All monitor VDD pins use MCU control power. AVDD and DVDD SENSE are separate remote wires, not substitute rail feeds.
CT via 10k to MCU selects nominal 200 ms release (140-260 ms). Sense pulldowns are local to this board.
30 us maximum fault detection applies only at specified 5% overdrive. No unconditional pre-E1 shutdown guarantee.

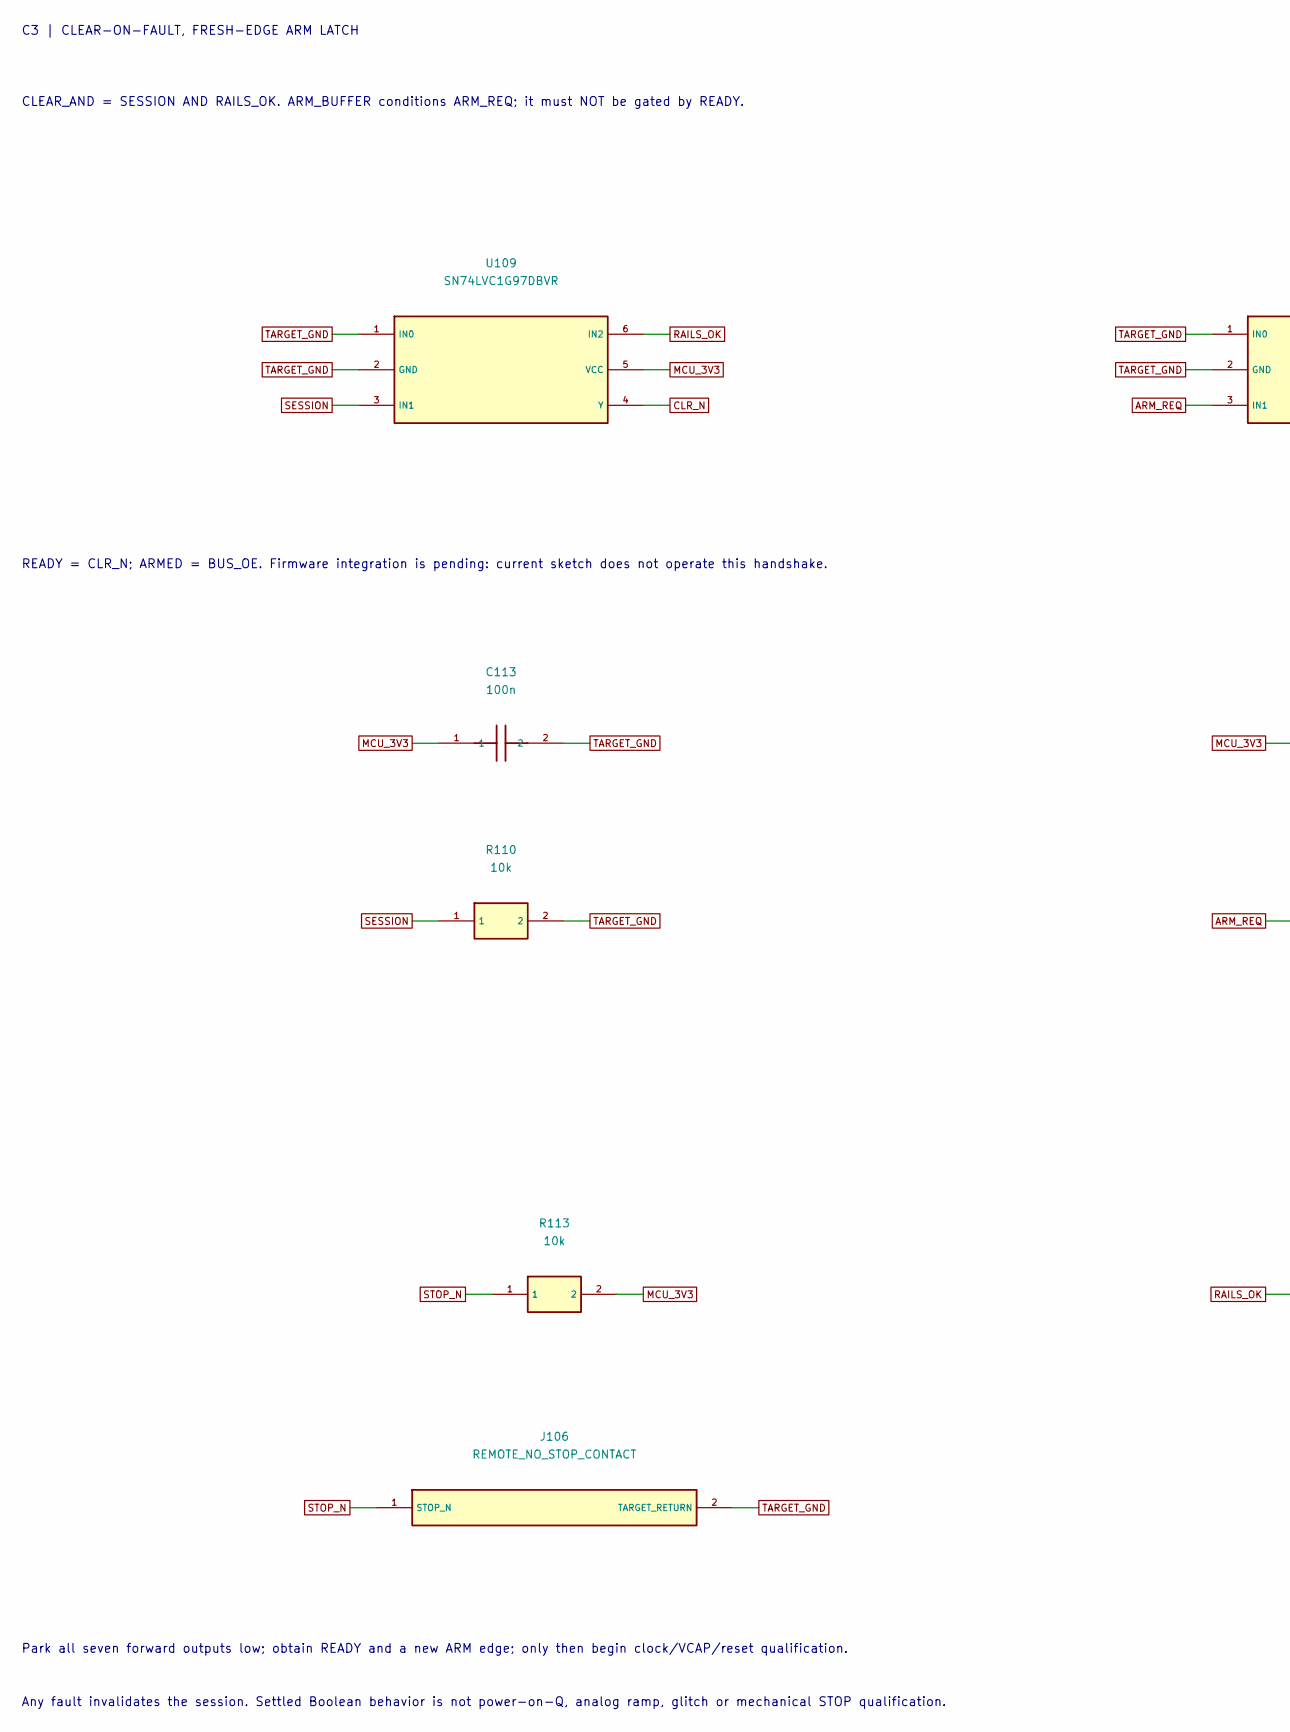
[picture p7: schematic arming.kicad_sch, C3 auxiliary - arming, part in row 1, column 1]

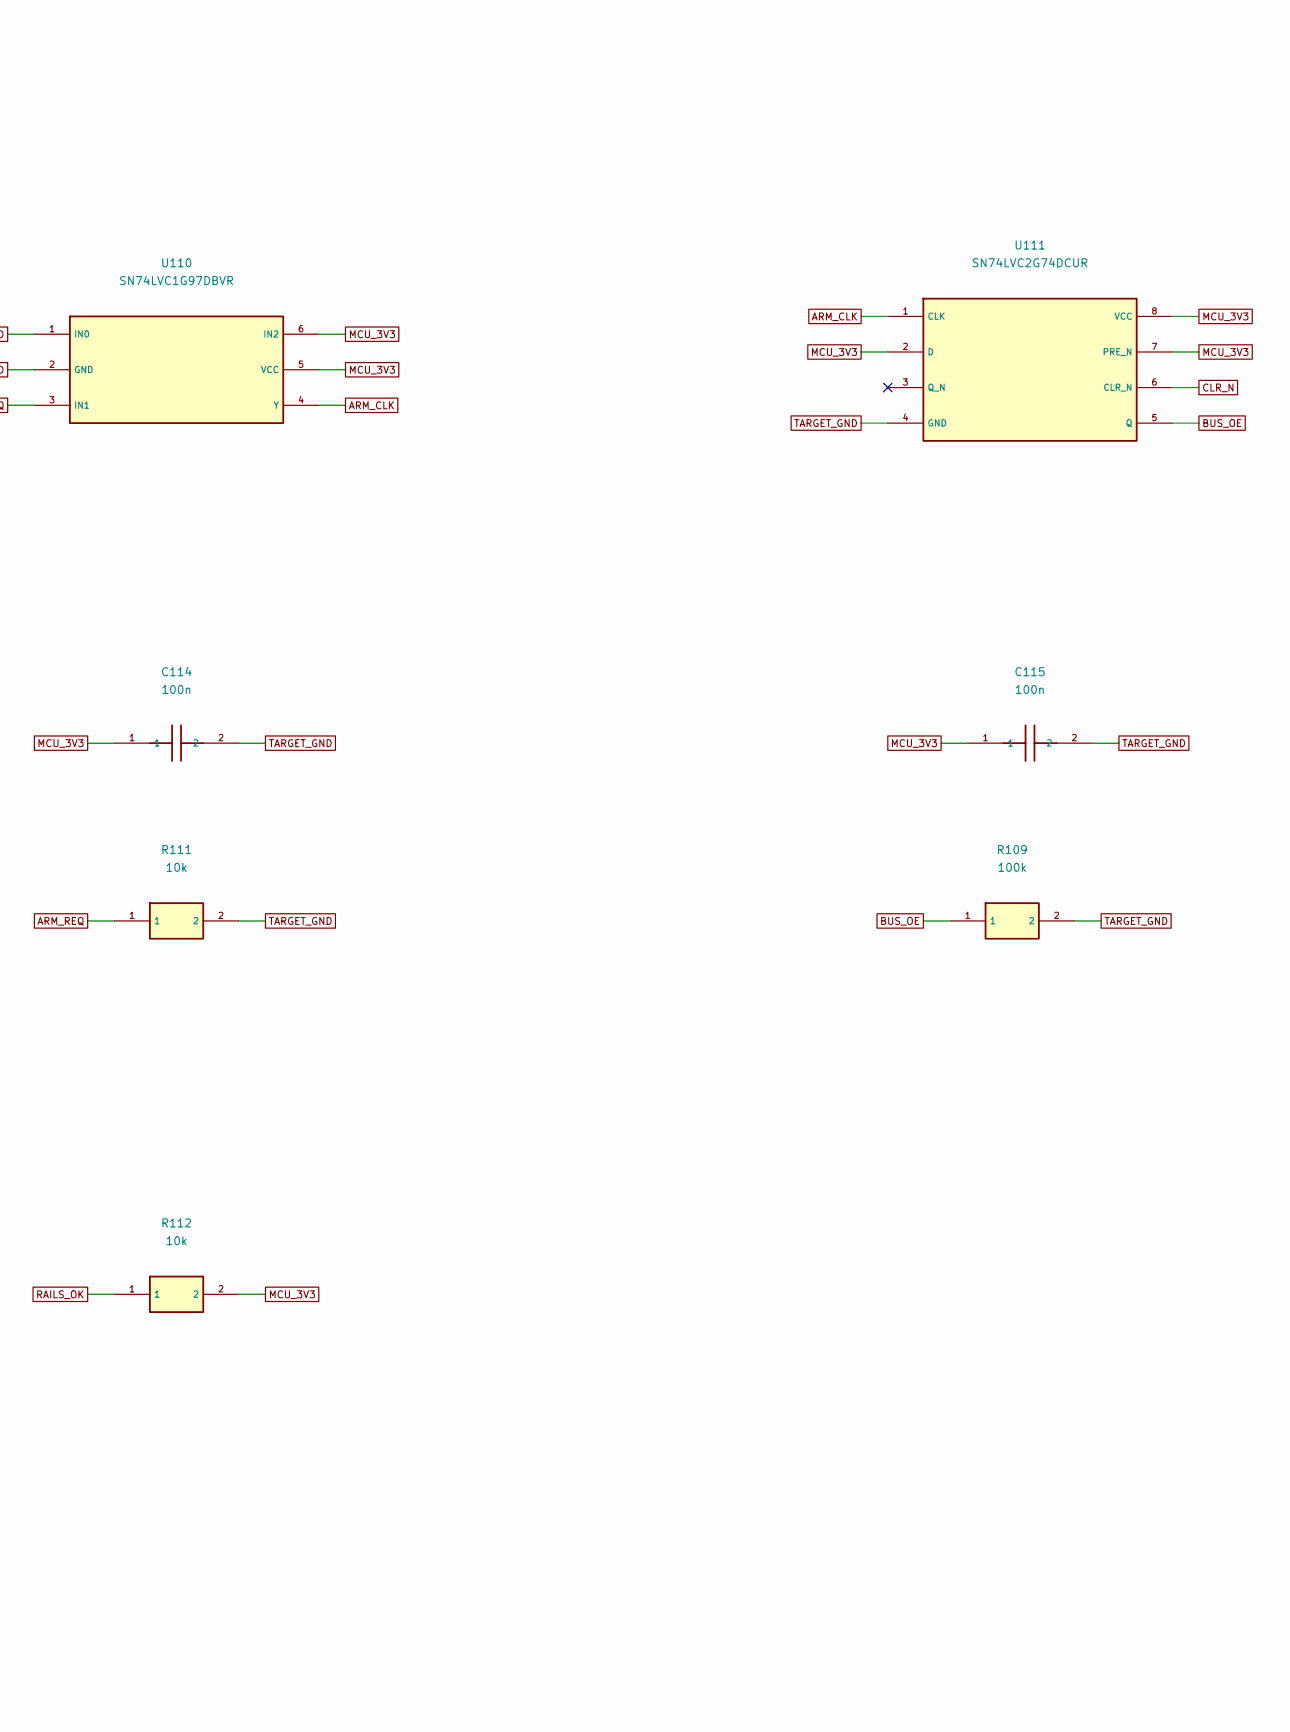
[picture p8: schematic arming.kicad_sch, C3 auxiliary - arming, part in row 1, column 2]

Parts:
C113, C114, C115: 100n; C_0603_1608Metric; MPN C0603C104K5RACTU
J106: REMOTE_NO_STOP_CONTACT; SolderTails_2; MPN PCB_LANDINGS_ONLY
R109: 100k; R_0603_1608Metric; MPN RC0603FR-07100KL
R110, R111, R112, R113: 10k; R_0603_1608Metric; MPN RC0603FR-0710KL
U109, U110: SN74LVC1G97DBVR; SOT-23-6; MPN SN74LVC1G97DBVR
U111: SN74LVC2G74DCUR; VSSOP-8_2.3x2mm_P0.5mm; MPN SN74LVC2G74DCUR

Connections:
ARM_CLK: U110.4 (Y), U111.1 (CLK)
ARM_REQ: R111.1, U110.3 (IN1); also elsewhere on the board
BUS_OE: R109.1, U111.5 (Q); also elsewhere on the board
CLR_N: U109.4 (Y), U111.6 (CLR_N); also elsewhere on the board
MCU_3V3: C113.1, C114.1, C115.1, R112.2, R113.2, U109.5 (VCC), U110.5 (VCC), U110.6 (IN2), U111.2 (D), U111.7 (PRE_N), U111.8 (VCC); also elsewhere on the board
RAILS_OK: R112.1, U109.6 (IN2); also elsewhere on the board
SESSION: R110.1, U109.3 (IN1); also elsewhere on the board
STOP_N: J106.1 (STOP_N), R113.1; also elsewhere on the board
TARGET_GND: C113.2, C114.2, C115.2, J106.2 (TARGET_RETURN), R109.2, R110.2, R111.2, U109.1 (IN0), U109.2 (GND), U110.1 (IN0), U110.2 (GND), U111.4 (GND); also elsewhere on the board

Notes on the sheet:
C3 | CLEAR-ON-FAULT, FRESH-EDGE ARM LATCH
CLEAR_AND = SESSION AND RAILS_OK. ARM_BUFFER conditions ARM_REQ; it must NOT be gated by READY.
READY = CLR_N; ARMED = BUS_OE. Firmware integration is pending: current sketch does not operate this handshake.
Park all seven forward outputs low; obtain READY and a new ARM edge; only then begin clock/VCAP/reset qualification.
Any fault invalidates the session. Settled Boolean behavior is not power-on-Q, analog ramp, glitch or mechanical STOP qualification.

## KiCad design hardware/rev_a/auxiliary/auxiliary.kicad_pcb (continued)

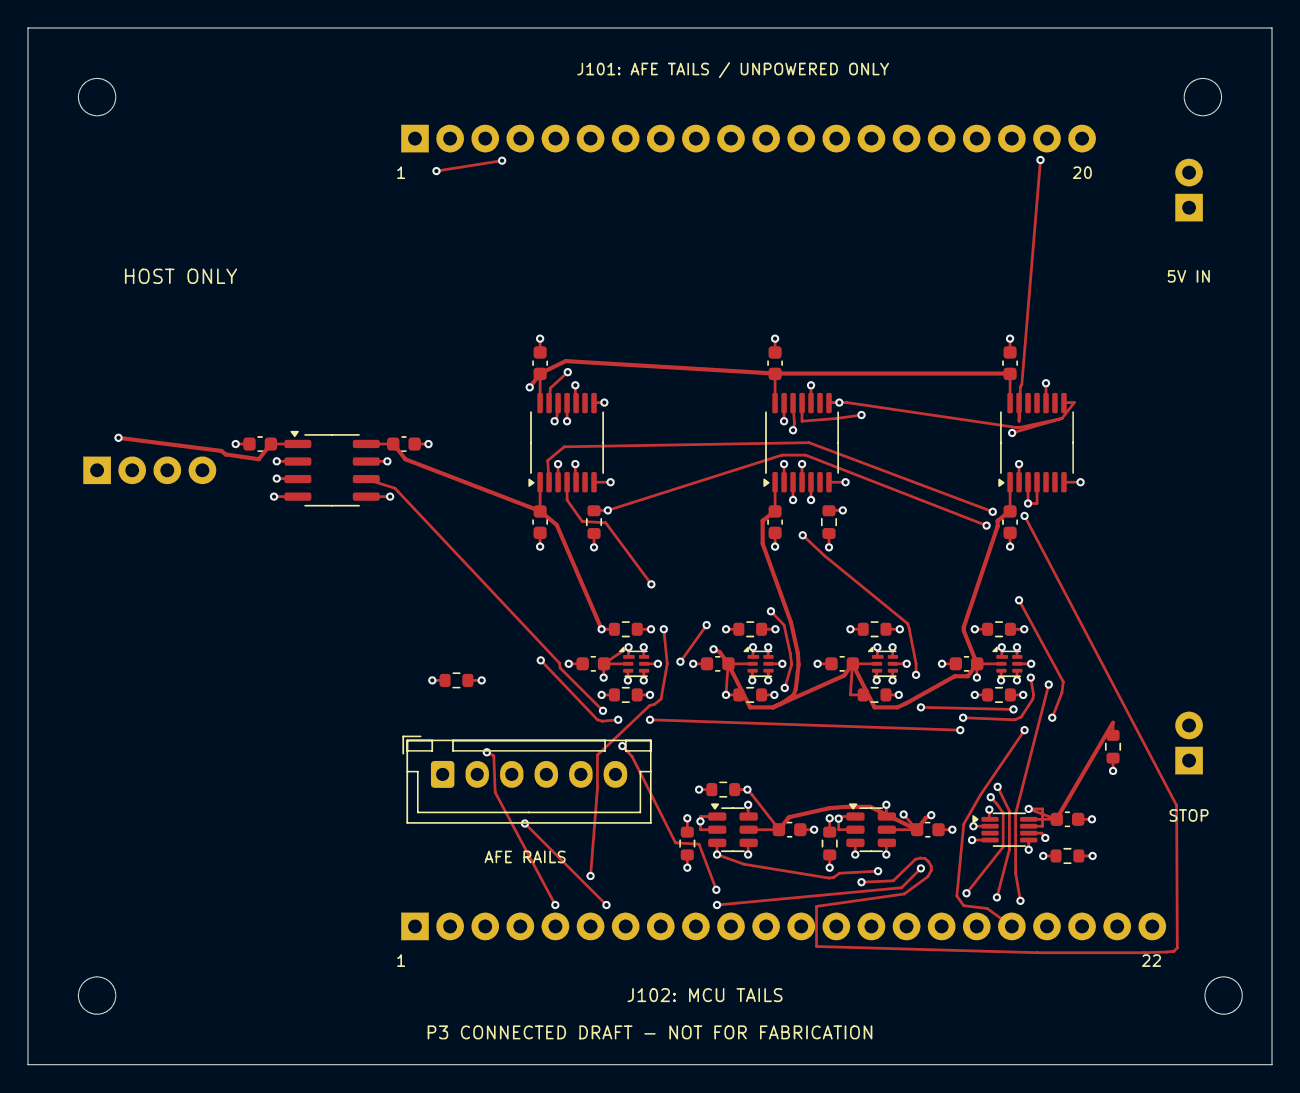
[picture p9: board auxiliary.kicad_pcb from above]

Board: 4 copper layers, 90.0 x 75.0 mm, 52 parts (0 on the bottom side), 41 nets.

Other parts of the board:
H1, H2, H3, H4: M2.5_CLEARANCE_ONLY; MountingHole_2.7mm_M2.5

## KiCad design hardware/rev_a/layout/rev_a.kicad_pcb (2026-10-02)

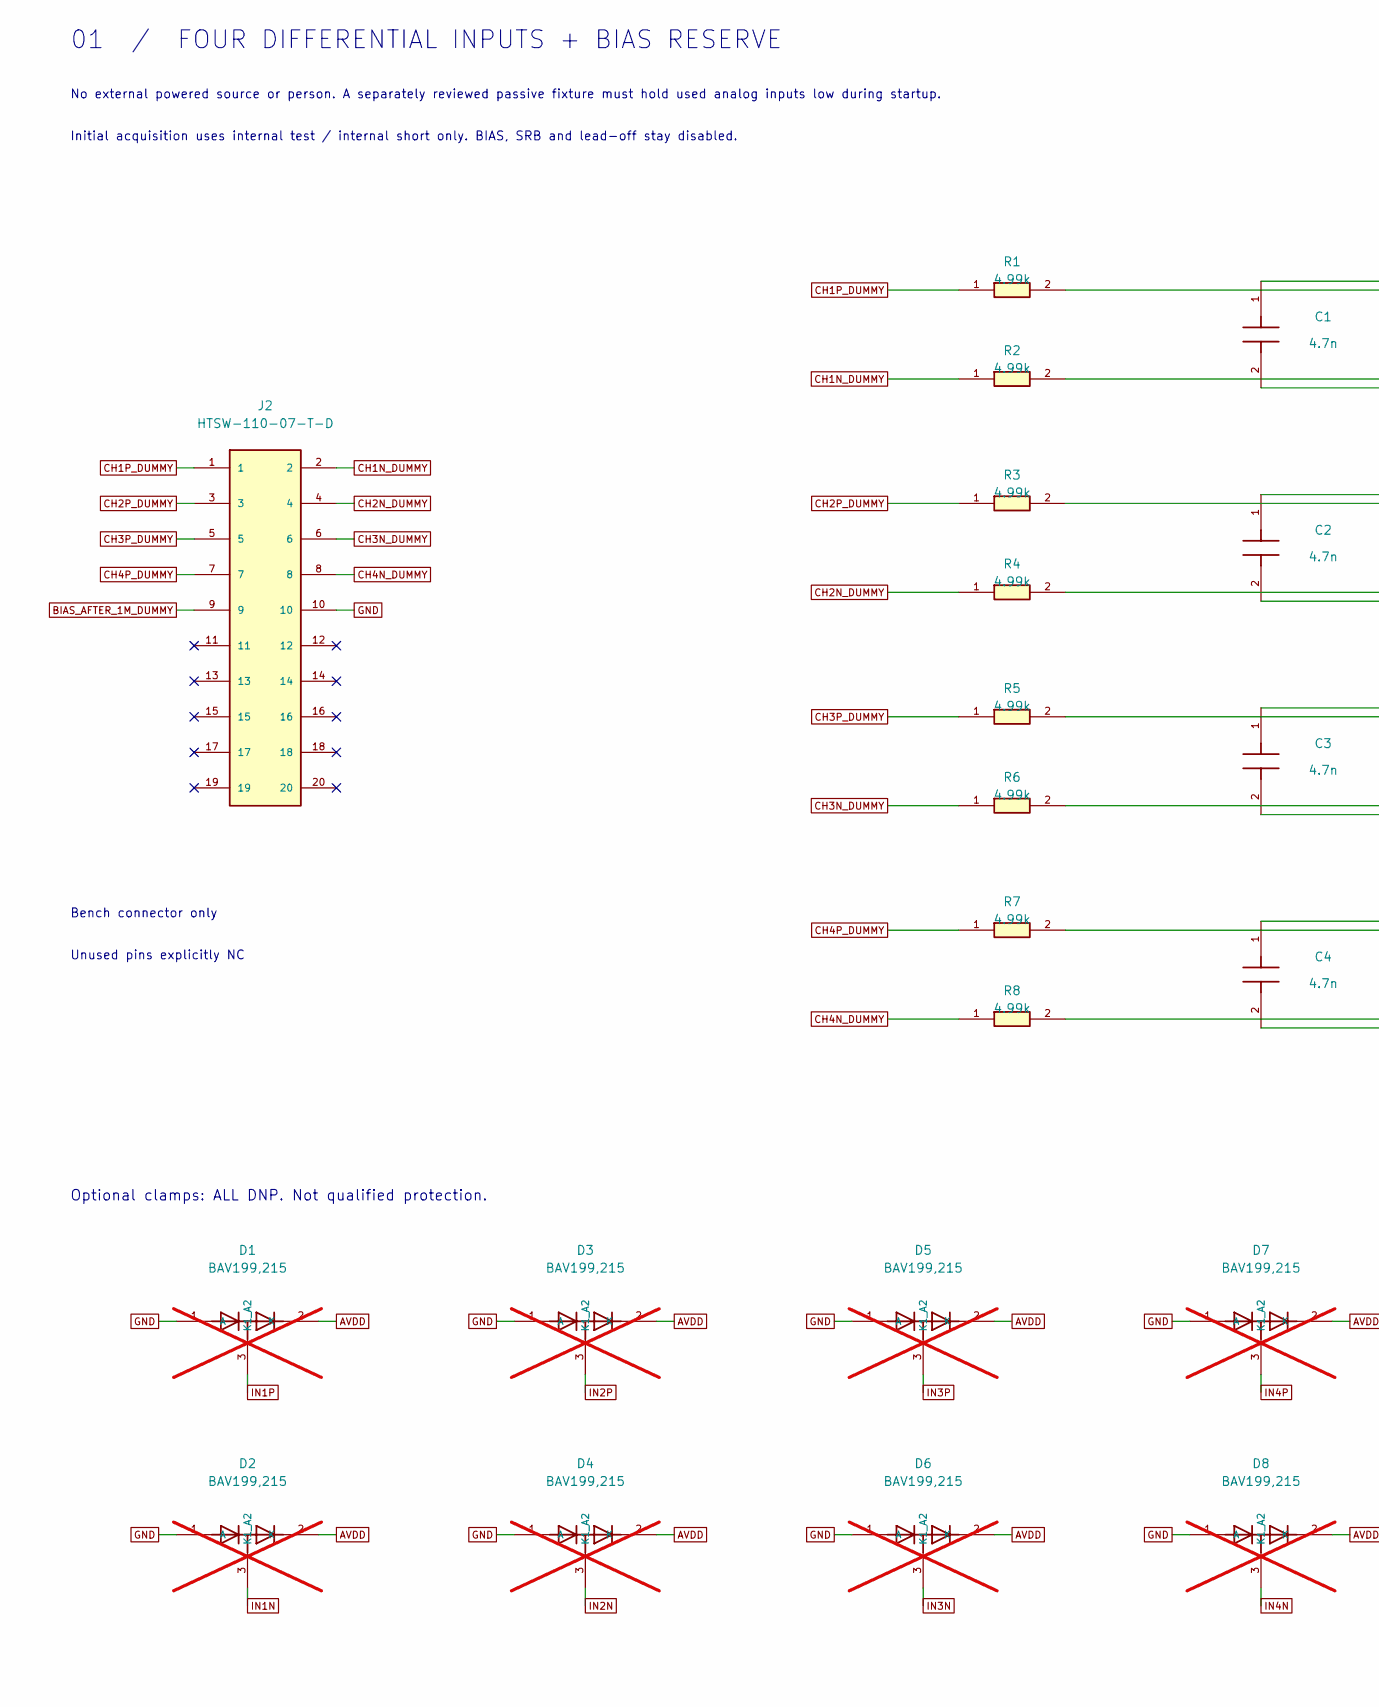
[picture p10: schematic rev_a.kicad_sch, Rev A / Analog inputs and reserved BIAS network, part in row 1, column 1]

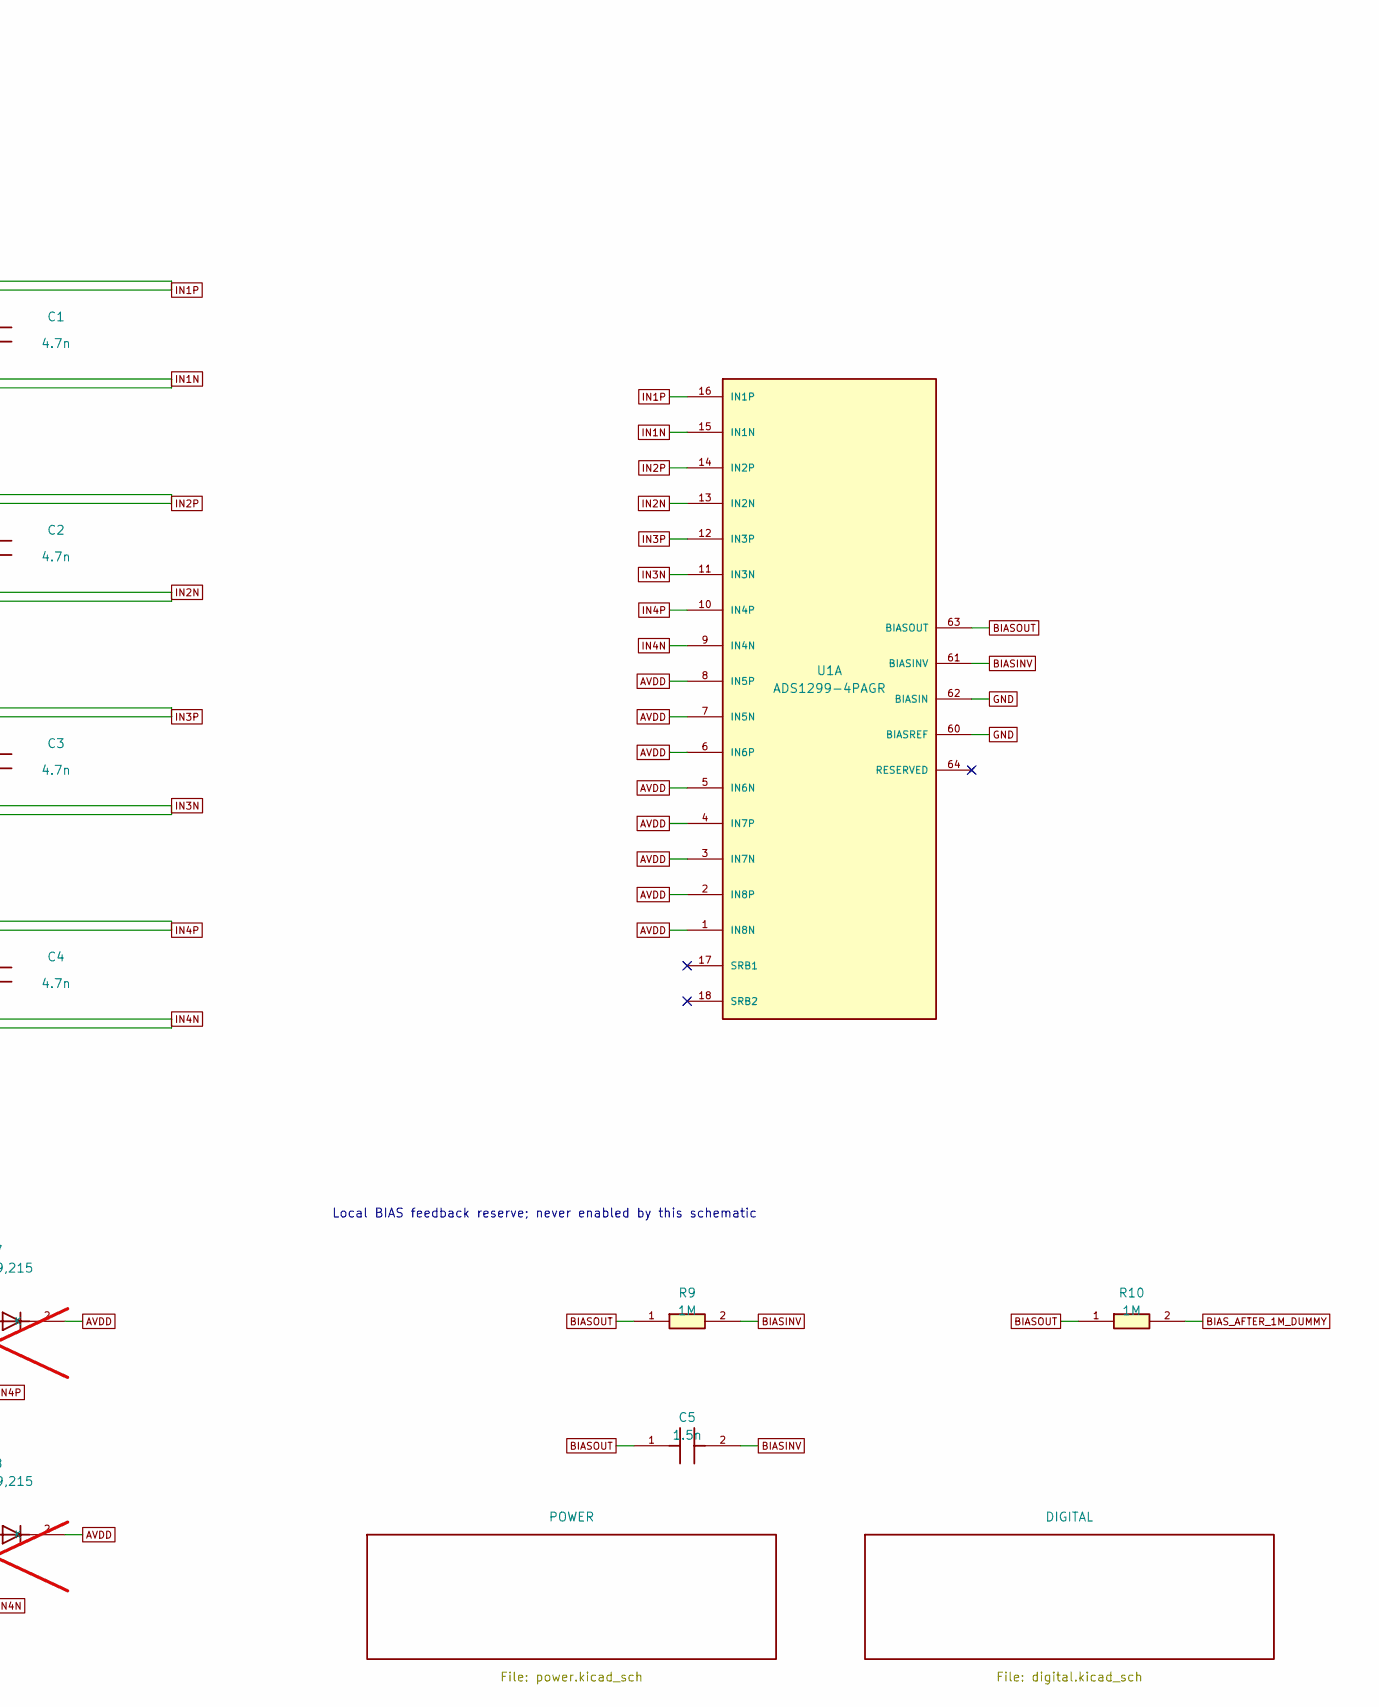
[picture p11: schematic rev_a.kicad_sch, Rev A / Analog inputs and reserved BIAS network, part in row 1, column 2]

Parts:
C1, C2, C3, C4: 4.7n; C_0603_1608Metric; Tolerance 0.05; MPN GRM1885C1H472JA01D
C5: 1.5n; C_0603_1608Metric; Tolerance 0.05; MPN GRM1885C1H152JA01D
D1, D2, D3, D4, D5, D6, D7, D8: BAV199,215; SOT-23; MPN BAV199,215; not fitted
J2: HTSW-110-07-T-D; PinHeader_2x10_P2.54mm_Vertical; MPN HTSW-110-07-T-D
R1, R2, R3, R4, R5, R6, R7, R8: 4.99k; R_0603_1608Metric; Tolerance 0.01; MPN RC0603FR-074K99L
R9, R10: 1M; R_0603_1608Metric; Tolerance 0.01; MPN RC0603FR-071ML
U1: ADS1299-4PAGR; TQFP-64_10x10mm_P0.5mm; MPN ADS1299-4PAGR

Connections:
AVDD: D1.2 (K), D2.2 (K), D3.2 (K), D4.2 (K), D5.2 (K), D6.2 (K), D7.2 (K), D8.2 (K), U1.1 (IN8N), U1.2 (IN8P), U1.3 (IN7N), U1.4 (IN7P), U1.5 (IN6N), U1.6 (IN6P), U1.7 (IN5N), U1.8 (IN5P); also elsewhere on the board
BIASINV: C5.2, R9.2, U1.61 (BIASINV)
BIASOUT: C5.1, R9.1, R10.1, U1.63 (BIASOUT)
BIAS_AFTER_1M_DUMMY: J2.9, R10.2
CH1N_DUMMY: J2.2, R2.1
CH1P_DUMMY: J2.1, R1.1
CH2N_DUMMY: J2.4, R4.1
CH2P_DUMMY: J2.3, R3.1
CH3N_DUMMY: J2.6, R6.1
CH3P_DUMMY: J2.5, R5.1
CH4N_DUMMY: J2.8, R8.1
CH4P_DUMMY: J2.7, R7.1
GND: D1.1 (A), D2.1 (A), D3.1 (A), D4.1 (A), D5.1 (A), D6.1 (A), D7.1 (A), D8.1 (A), J2.10, U1.60 (BIASREF), U1.62 (BIASIN); also elsewhere on the board
IN1N: C1.2, D2.3 (K1_A2), R2.2, U1.15 (IN1N)
IN1P: C1.1, D1.3 (K1_A2), R1.2, U1.16 (IN1P)
IN2N: C2.2, D4.3 (K1_A2), R4.2, U1.13 (IN2N)
IN2P: C2.1, D3.3 (K1_A2), R3.2, U1.14 (IN2P)
IN3N: C3.2, D6.3 (K1_A2), R6.2, U1.11 (IN3N)
IN3P: C3.1, D5.3 (K1_A2), R5.2, U1.12 (IN3P)
IN4N: C4.2, D8.3 (K1_A2), R8.2, U1.9 (IN4N)
IN4P: C4.1, D7.3 (K1_A2), R7.2, U1.10 (IN4P)

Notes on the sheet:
01 / FOUR DIFFERENTIAL INPUTS + BIAS RESERVE
No external powered source or person. A separately reviewed passive fixture must hold used analog inputs low during startup.
Initial acquisition uses internal test / internal short only. BIAS, SRB and lead-off stay disabled.
Bench connector only
Unused pins explicitly NC
Local BIAS feedback reserve; never enabled by this schematic
Optional clamps: ALL DNP. Not qualified protection.

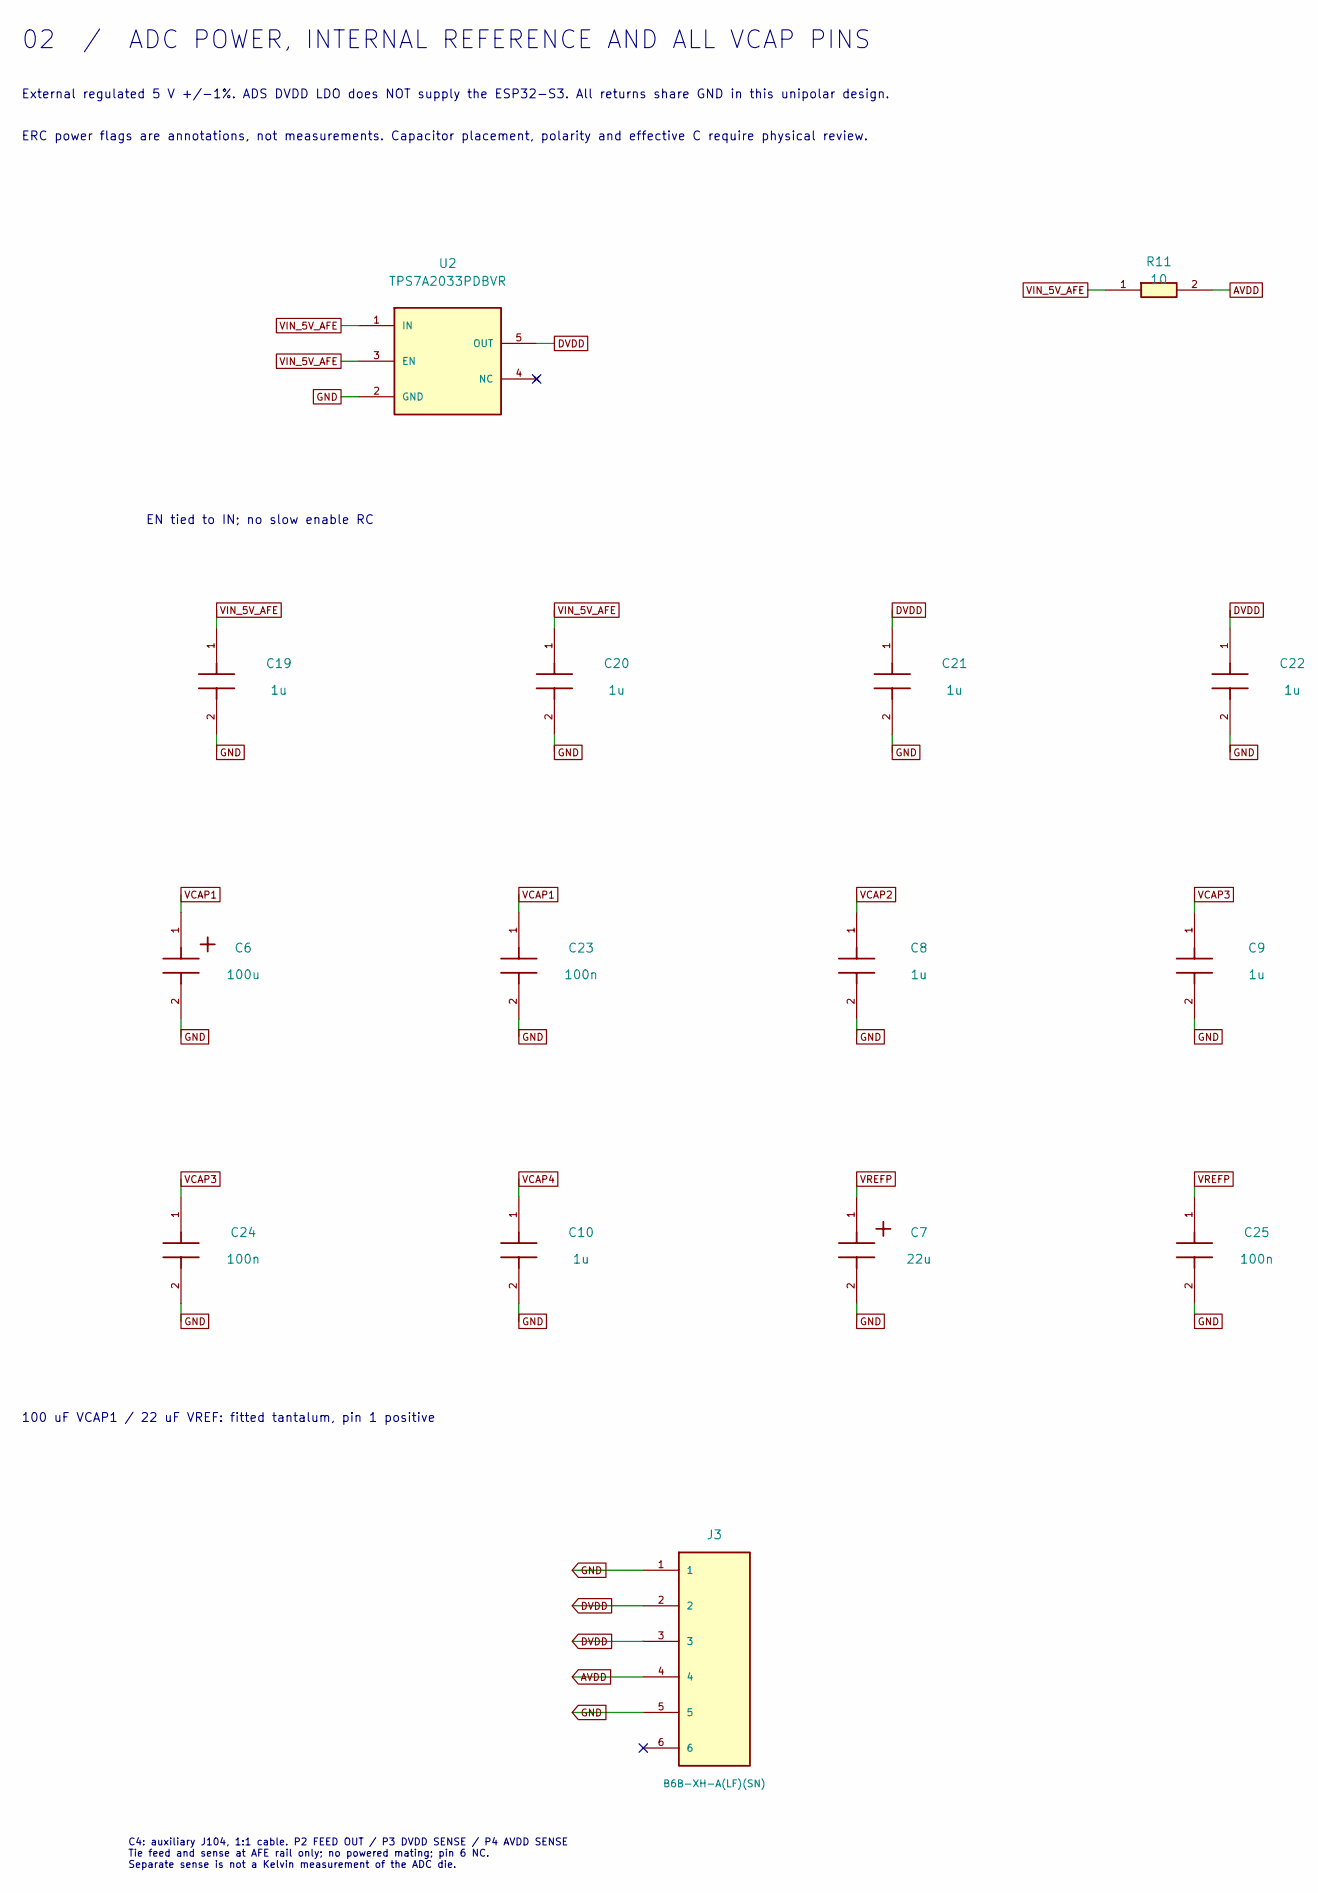
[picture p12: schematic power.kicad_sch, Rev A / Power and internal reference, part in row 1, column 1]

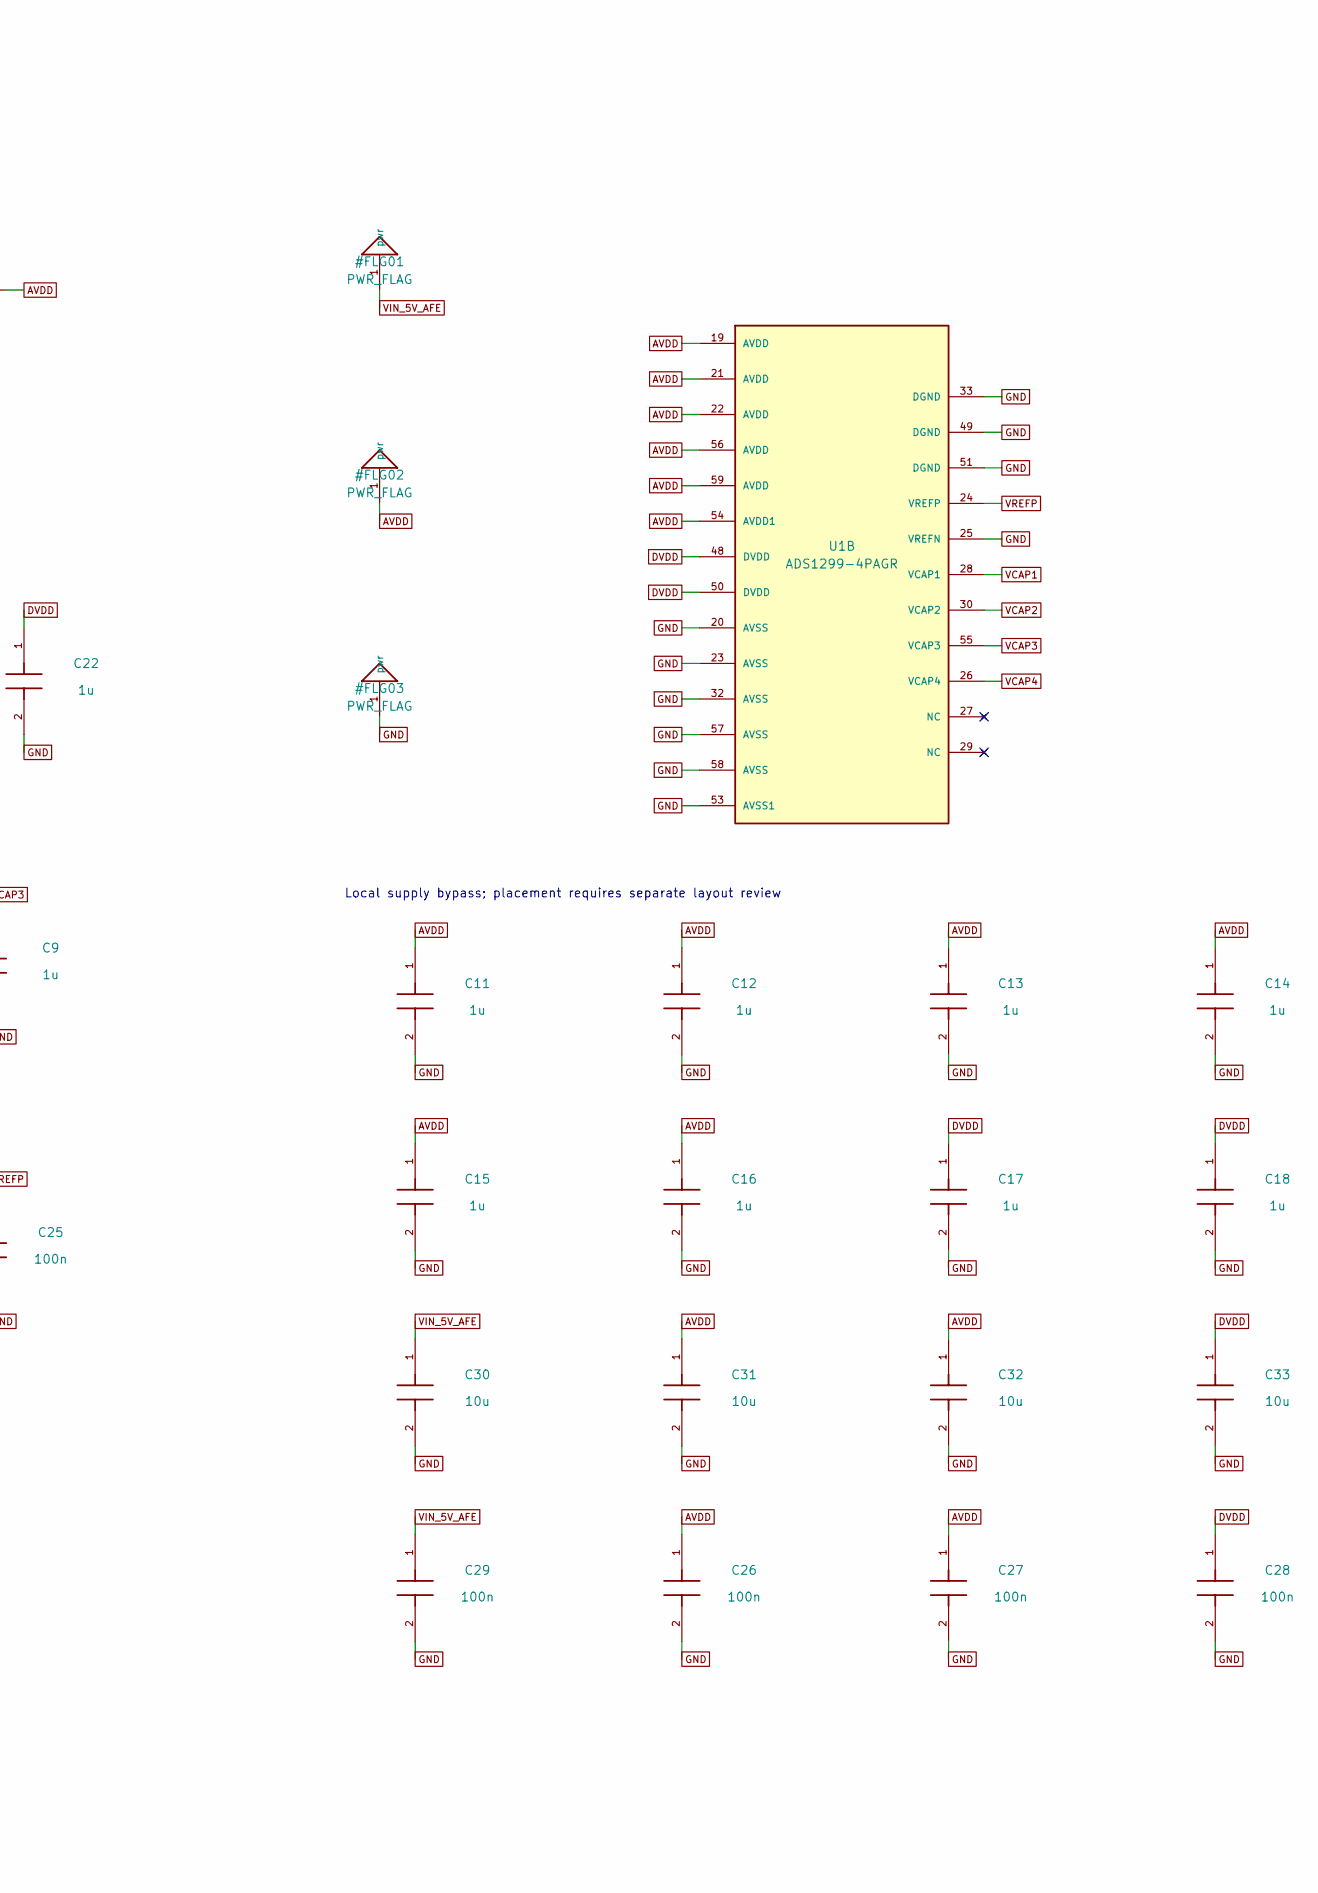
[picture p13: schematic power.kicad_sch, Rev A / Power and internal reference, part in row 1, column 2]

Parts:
C6: 100u; T491D_7343_DensityB; Tolerance 0.1; MPN T491D107K016AT
C7: 22u; T491B_3528_DensityB; Tolerance 0.1; MPN T491B226K016AT
C8, C9, C10, C11, C12, C13, C14, C15, C16, C17, C18, C19, C20, C21, C22: 1u; C_0603_1608Metric; Tolerance 0.1; MPN GRM188R61E105KA12D
C23, C24, C25, C26, C27, C28, C29: 100n; C_0603_1608Metric; Tolerance 0.1; MPN GRM188R71H104KA93D
C30, C31, C32, C33: 10u; C_0805_2012Metric; Tolerance 0.1; MPN GRM219R61A106KE44D
J3: B6B-XH-A(LF)(SN); JST_XH_B6B-XH-A_1x06_P2.50mm_Vertical; MPN B6B-XH-A(LF)(SN)
R11: 10; R_0603_1608Metric; Tolerance 0.01; MPN RC0603FR-0710RL
U1: ADS1299-4PAGR; TQFP-64_10x10mm_P0.5mm; MPN ADS1299-4PAGR
U2: TPS7A2033PDBVR; SOT-23-5; MPN TPS7A2033PDBVR

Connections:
AVDD: C11.1, C12.1, C13.1, C14.1, C15.1, C16.1, C26.1, C27.1, C31.1, C32.1, J3.4, R11.2, U1.19 (AVDD), U1.21 (AVDD), U1.22 (AVDD), U1.54 (AVDD1), U1.56 (AVDD), U1.59 (AVDD); also elsewhere on the board
DVDD: C17.1, C18.1, C21.1, C22.1, C28.1, C33.1, J3.2, J3.3, U1.48 (DVDD), U1.50 (DVDD), U2.5 (OUT)
GND: C6.2, C7.2, C8.2, C9.2, C10.2, C11.2, C12.2, C13.2, C14.2, C15.2, C16.2, C17.2, C18.2, C19.2, C20.2, C21.2, C22.2, C23.2, C24.2, C25.2, C26.2, C27.2, C28.2, C29.2, C30.2, C31.2, C32.2, C33.2, J3.1, J3.5, U1.20 (AVSS), U1.23 (AVSS), U1.25 (VREFN), U1.32 (AVSS), U1.33 (DGND), U1.49 (DGND), U1.51 (DGND), U1.53 (AVSS1), U1.57 (AVSS), U1.58 (AVSS), U2.2 (GND); also elsewhere on the board
VCAP1: C6.1, C23.1, U1.28 (VCAP1)
VCAP2: C8.1, U1.30 (VCAP2)
VCAP3: C9.1, C24.1, U1.55 (VCAP3)
VCAP4: C10.1, U1.26 (VCAP4)
VIN_5V_AFE: C19.1, C20.1, C29.1, C30.1, R11.1, U2.1 (IN), U2.3 (EN); also elsewhere on the board
VREFP: C7.1, C25.1, U1.24 (VREFP)

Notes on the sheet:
02 / ADC POWER, INTERNAL REFERENCE AND ALL VCAP PINS
External regulated 5 V +/-1%. ADS DVDD LDO does NOT supply the ESP32-S3. All returns share GND in this unipolar design.
ERC power flags are annotations, not measurements. Capacitor placement, polarity and effective C require physical review.
EN tied to IN; no slow enable RC
100 uF VCAP1 / 22 uF VREF: fitted tantalum, pin 1 positive
Local supply bypass; placement requires separate layout review
C4: auxiliary J104, 1:1 cable. P2 FEED OUT / P3 DVDD SENSE / P4 AVDD SENSE Tie feed and sense at AFE rail only; no powered mating; pin 6 NC. Separate sense is not a Kelvin measurement of the ADC die.



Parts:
J1: HTSW-110-07-T-D; PinHeader_2x10_P2.54mm_Vertical; MPN HTSW-110-07-T-D
MOD1: ESP32-S3-DevKitC-1-N8R8; MPN ESP32-S3-DevKitC-1-N8R8
R12, R13, R15, R16, R17, R18, R19: 42.2k; R_0603_1608Metric; Tolerance 0.01; MPN RC0603FR-0742K2L
R14, R20, R21, R22, R23: 10k; R_0603_1608Metric; Tolerance 0.01; MPN RC0603FR-0710KL
U1: ADS1299-4PAGR; TQFP-64_10x10mm_P0.5mm; MPN ADS1299-4PAGR

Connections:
CLK: R14.1, U1.37 (CLK)
CLKSEL: J1.19, MOD1.GPIO8, R13.1, U1.52 (CLKSEL)
CS: J1.7, MOD1.GPIO10, R12.1, U1.39 (CS)
DRDY: J1.9, MOD1.GPIO4, U1.47 (DRDY)
GND: J1.2, J1.4, J1.6, J1.8, J1.10, J1.12, J1.14, J1.16, J1.18, J1.20, MOD1.GND, R12.2, R13.2, R14.2, R15.2, R16.2, R17.2, R18.2, R19.2, R20.2, R21.2, R22.2, R23.2, U1.31 (RESV1), U1.41 (DAISY_IN); also elsewhere on the board
GPIO1: R20.1, U1.42 (GPIO1)
GPIO2: R21.1, U1.44 (GPIO2)
GPIO3: R22.1, U1.45 (GPIO3)
GPIO4: R23.1, U1.46 (GPIO4)
MISO: J1.5, MOD1.GPIO13, U1.43 (DOUT)
MOSI: J1.3, MOD1.GPIO11, R19.1, U1.34 (DIN)
PWDN: J1.15, MOD1.GPIO7, R16.1, U1.35 (PWDN)
RESET: J1.11, MOD1.GPIO5, R15.1, U1.36 (RESET)
SCLK: J1.1, MOD1.GPIO12, R18.1, U1.40 (SCLK)
START: J1.13, MOD1.GPIO6, R17.1, U1.38 (START)
VIN_5V_AFE: J1.17, MOD1.5V (5V input); also elsewhere on the board

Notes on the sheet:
03 / DIGITAL INTERFACE AND DEFINED STARTUP STATES
All seven driven ADS inputs start low. CLKSEL goes high only after the reviewed firmware rail/fixture acknowledgment.
Independent ADS/MCU rails: boot, reset and loss-of-rail back-powering remain OPEN electrical review items. No automatic interlock.
OFF-BOARD / logical GPIO identifiers
Not a devkit footprint or physical header pin map.
Power from the same external 5 V source; NO simultaneous USB power.
DAISY_IN (41) and RESV1 (31) connect directly to GND. CLK (37) has its own 10k pulldown.
CS, RESET and PWDN are active-low controls. This is a bench review candidate, not a released interface.


Board: 4 copper layers, 78.0 x 58.0 mm, 69 parts (0 on the bottom side), 42 nets.

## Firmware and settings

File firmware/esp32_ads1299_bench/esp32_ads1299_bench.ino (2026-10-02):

/*
  BENCH ONLY. No electrode on a person, including bias/reference electrodes.
  Requires a fully populated, documented ADS1299-x AFE board, 3.3-V digital
  interface, internal oscillator and internal-reference support. The board's
  analog power arrangement is NOT supplied by this sketch or pin map.

  Validation scopes: portable helper tests, target compilation and physical
  measurements are separate. See docs/ESP32_S3_TARGET_BUILD.md for exact build
  evidence. No "passed tests" claim authorizes GPIO or human connection.
*/
#include <Arduino.h>
#include <SPI.h>
#include <WiFi.h>
#include <WiFiUdp.h>
#include "board_config.h"
#include "portable_core.h"
#if defined(EEGLAB_REV_A_S3)
#include <driver/gpio.h>
#include "rev_a_startup.h"
#include "c2_interlock.h"
#endif

// Target guards live with the explicit profile selection in board_config.h.

SPISettings settings(1000000,MSBFIRST,SPI_MODE1);
WiFiUDP udp;
IPAddress host;
portMUX_TYPE irqMux=portMUX_INITIALIZER_UNLOCKED;
volatile uint32_t edgeCount=0,edgeMicros=0;
uint32_t consumed=0,overruns=0,lastGoodMs=0;
uint8_t channels=0;
bool spiOpened=false,transactionOpen=false;
#if defined(EEGLAB_REV_A_S3)
eeglab::C2Interlock interlock;
bool controlsConfigured=false;
#endif
void requireBus();
[[noreturn]] void fail(const char* why);
void waitBenchMs(unsigned value) {
    for(unsigned i=0;i<value;++i){requireBus();delay(1);}
    requireBus();
}


void IRAM_ATTR onDataReady() {
    portENTER_CRITICAL_ISR(&irqMux);
    ++edgeCount;edgeMicros=micros();
    portEXIT_CRITICAL_ISR(&irqMux);
}
void snapshot(uint32_t &count,uint32_t &tick) {
    portENTER_CRITICAL(&irqMux);
    count=edgeCount;tick=edgeMicros;
    portEXIT_CRITICAL(&irqMux);
}
[[noreturn]] void fail(const char* why) {
#if defined(EEGLAB_REV_A_S3)
    // Drop SESSION BEFORE potentially blocking console or peripheral teardown.
    // Best-effort GPIO cleanup is not protection against a failed MCU/rail.
    if(interlock.started()) {
        interlock.invalidate();
        gpio_set_level(static_cast<gpio_num_t>(eeglab::C2_SESSION),0);
        gpio_set_level(static_cast<gpio_num_t>(eeglab::C2_ARM_REQ),0);
        detachInterrupt(digitalPinToInterrupt(PIN_DRDY));
        if(transactionOpen){SPI.endTransaction();transactionOpen=false;}
        if(spiOpened){SPI.end();spiOpened=false;}
        constexpr int controls[]={PIN_SCLK,PIN_MOSI,PIN_CS,PIN_RESET,PIN_START,PIN_PWDN,PIN_CLKSEL};
        for(int pin:controls)gpio_set_level(static_cast<gpio_num_t>(pin),0);
        if(controlsConfigured)for(int pin:controls)pinMode(pin,OUTPUT);
        portENTER_CRITICAL(&irqMux);
        edgeCount=0;edgeMicros=0;
        portEXIT_CRITICAL(&irqMux);
        channels=0;consumed=0;overruns=0;lastGoodMs=0;
    }
#else
    digitalWrite(PIN_START,LOW);
    digitalWrite(PIN_PWDN,LOW); // START low alone does not cancel a command-started conversion
    #endif
    Serial.print("\nHALTED / BENCH ONLY; CAPTURE INVALID: ");Serial.println(why);
    while(true)delay(1000);
}
void selectChip() {
    requireBus();SPI.beginTransaction(settings);transactionOpen=true;
    requireBus();digitalWrite(PIN_CS,LOW);delayMicroseconds(3);
}
void releaseChip() {
    requireBus();delayMicroseconds(3);requireBus();digitalWrite(PIN_CS,HIGH);
    SPI.endTransaction();transactionOpen=false;delayMicroseconds(3);requireBus();
}
uint8_t busTransfer(uint8_t value) {
    requireBus();const auto received=SPI.transfer(value);requireBus();return received;
}
void command(uint8_t op) { selectChip();busTransfer(op);delayMicroseconds(3);releaseChip(); }
void writeReg(uint8_t addr,uint8_t value) {
    selectChip();busTransfer(0x40|addr);delayMicroseconds(3);
    busTransfer(0);delayMicroseconds(3);busTransfer(value);delayMicroseconds(3);releaseChip();
}
uint8_t readReg(uint8_t addr) {
    selectChip();busTransfer(0x20|addr);delayMicroseconds(3);
    busTransfer(0);delayMicroseconds(3);uint8_t r=busTransfer(0);releaseChip();return r;
}
void checkedReg(uint8_t addr,uint8_t value,uint8_t mask=0xff) {
    writeReg(addr,value);
    if((readReg(addr)&mask)!=(value&mask))fail("Register readback mismatch; inspect supply/clock/SPI.");
}
#if defined(EEGLAB_REV_A_S3)
struct C2Io {
    void level(int pin,int value) {
        const auto status=gpio_set_level(static_cast<gpio_num_t>(pin),value);
        if(status!=ESP_OK)fail("C2 GPIO latch operation failed.");
    }
    void output(int pin) { pinMode(pin,OUTPUT); }
    void inputPulldown(int pin) { pinMode(pin,INPUT_PULLDOWN); }
    bool read(int pin) { return digitalRead(pin)==HIGH; }
    uint32_t nowUs() { return micros(); }
    void waitUs(unsigned value) { delayMicroseconds(value); }
};
C2Io c2io;
#endif
void requireBus() {
#if defined(EEGLAB_REV_A_S3)
    if(!interlock.valid(c2io))fail("C2 not armed or rail fault; restart the complete reviewed sequence.");
#endif
}
#if defined(EEGLAB_REV_A_S3)
void awaitBenchKey(char key, const char* message) {
    // Ignore queued acknowledgments: each measurement needs a fresh response.
    while(Serial.available()>0) {
        if(interlock.monitoring())requireBus();
        Serial.read();
    }
    if(interlock.monitoring())requireBus();
    Serial.println(message);
    while(true) {
        if(interlock.monitoring())requireBus();
        if(Serial.available()>0 && Serial.read()==key) {
            if(interlock.monitoring())requireBus();
            return;
        }
        delay(10);
    }
}
struct RevAStartupIo {
    void level(int pin, int value) {
        if(value || interlock.monitoring())requireBus();
        // ESP-IDF permits setting the output latch before pinMode enables it.
        // Arduino digitalWrite before pinMode is not a portable substitute.
        if(gpio_set_level(static_cast<gpio_num_t>(pin),value)!=ESP_OK) {
            fail("GPIO latch operation failed.");
        }
    }
    void output(int pin) { pinMode(pin,OUTPUT); }
    void waitMs(unsigned value) { waitBenchMs(value); }
    void waitUs(unsigned value) { requireBus();delayMicroseconds(value);requireBus(); }
    void confirmRailsAndInputs() {
        controlsConfigured=true;
        awaitBenchKey('R',"BENCH: verify ADS rails stable and passive startup fixture holds analog inputs low; then type R. No body or powered source.");
        if(!interlock.arm(c2io))fail("C2 fresh arm failed; no automatic retry.");
    }
    void confirmVcap1() {
        awaitBenchKey('V',"BENCH: measure VCAP1 > 1.1 V with ADS rails still stable; then type V. This firmware does not sense those voltages.");
    }
};
#endif
void setup() {
#if defined(EEGLAB_REV_A_S3)
    // The distributed false review gate retains the onboard UART console.
    // External-console pins are not configured before exact interface review.
    if(BOARD_PROFILE_REVIEWED) {
        Serial.begin(CONSOLE_BAUD, SERIAL_8N1, CONSOLE_RX, CONSOLE_TX);
    } else {
        Serial.begin(460800);
    }
#else
    Serial.begin(460800);
#endif
    delay(500);
    Serial.println("ADS1299 learning lab. BENCH ONLY; remove ALL body electrodes.");
    if(!BOARD_PROFILE_REVIEWED) {
        // No ADS control pin is configured until this gate is acknowledged.
        Serial.println("Set BOARD_PROFILE_REVIEWED only after reviewing your exact board and power rails.");
        while(true)delay(1000);
    }
#if defined(EEGLAB_REV_A_S3)
    if(!interlock.prepare(c2io))fail("C2 did not clear while SESSION was low.");
    RevAStartupIo startup;
    eeglab::startRevA(startup);
#else
    pinMode(PIN_CS,OUTPUT);digitalWrite(PIN_CS,HIGH);
    pinMode(PIN_START,OUTPUT);digitalWrite(PIN_START,LOW);
    pinMode(PIN_RESET,OUTPUT);digitalWrite(PIN_RESET,LOW);
    pinMode(PIN_PWDN,OUTPUT);digitalWrite(PIN_PWDN,HIGH);
#endif
    pinMode(PIN_DRDY,INPUT);
    requireBus();
    SPI.begin(PIN_SCLK,PIN_MISO,PIN_MOSI,PIN_CS);
    spiOpened=true;
    requireBus();
#if !defined(EEGLAB_REV_A_S3)
    delay(500);digitalWrite(PIN_RESET,HIGH);delay(500);
#endif
    command(0x11); // SDATAC: stop read-data-continuous before register access
    command(0x0a); // STOP: pin START is held low; START/STOP commands control conversion
    const uint8_t id=readReg(0);
    if((id&0x1c)!=0x1c||(id&3)==3)fail("Not a recognized ADS1299-x ID.");
    channels=4+2*(id&3);
#if defined(EEGLAB_REV_A_S3)
    if(channels!=EXPECTED_ADS_CHANNELS)fail("Selected Rev A profile requires ADS1299-4.");
#endif
    Serial.printf("ID=0x%02x; %u physical channels; 250 SPS; gain 24\n",id,channels);
    checkedReg(0x01,0x96); // 250 SPS at 2.048-MHz clock, clock output disabled
    checkedReg(0x02,USE_INTERNAL_TEST?0xd0:0xc0); // ~0.9765625-Hz internal test, or test off
    checkedReg(0x03,0xe0,0xfe); // internal reference ON; bias driver OFF; ignore read-only BIAS_STAT
    checkedReg(0x04,0); // no lead-off excitation
    for(uint8_t i=0;i<channels;++i)checkedReg(0x05+i,USE_INTERNAL_TEST?0x65:0x61);
    for(uint8_t addr=0x0d;addr<=0x11;++addr)checkedReg(addr,0); // bias and lead-off sense OFF
    checkedReg(0x15,0); // SRB1 OFF
    checkedReg(0x17,0); // continuous conversions, lead-off comparator OFF
    waitBenchMs(500); // reference settling; verify actual reference capacitors/voltage on bench
    if(USE_WIFI_UDP) {
        if(!host.fromString(UDP_HOST))fail("Invalid UDP_HOST");
        requireBus();WiFi.mode(WIFI_STA);WiFi.begin(WIFI_SSID,WIFI_PASSWORD);requireBus();
        uint32_t start=millis();
        while(WiFi.status()!=WL_CONNECTED&&millis()-start<15000)waitBenchMs(100);
        if(WiFi.status()!=WL_CONNECTED)fail("Wi-Fi timeout");
        requireBus();WiFi.setSleep(false);requireBus();
        if(!udp.begin(9001))fail("UDP initialization failed");
        requireBus();
    }
    attachInterrupt(digitalPinToInterrupt(PIN_DRDY),onDataReady,FALLING);
    command(0x10); // RDATAC
    command(0x08); // START while physical START stays low
    requireBus();lastGoodMs=millis();
}
void loop() {
    requireBus();
    uint32_t seq,tick;snapshot(seq,tick);
    if(seq==consumed) {
        if(millis()-lastGoodMs>2000)fail("No valid data for 2 s; inspect DRDY and clock.");
        delayMicroseconds(50);return;
    }
    overruns+=(seq-consumed)-1; // DRDY edges not serviced are never silently invented
    consumed=seq;
    uint8_t frame[27];
    selectChip();
    for(uint8_t i=0;i<3+3*channels;++i)frame[i]=busTransfer(0);
    releaseChip();
    uint32_t after,afterTick;snapshot(after,afterTick);
    if(after!=seq){++overruns;return;} // conversion changed while reading: discard candidate
    if((frame[0]&0xf0)!=0xc0)fail("Invalid native status prefix; SPI frame alignment failed.");
    uint8_t wire[eeglab::MAX_PACKET_SIZE];
    const uint8_t flags=(USE_INTERNAL_TEST?1:2)|(overruns?8:0);
    const std::size_t size=eeglab::packet(wire,sizeof(wire),frame,channels,24,250,flags,seq,tick,overruns);
    if(size==0)fail("Packet encoding failed");
    requireBus();
    if(USE_WIFI_UDP) {
        if(udp.beginPacket(host,UDP_PORT)) {
            requireBus();udp.write(wire,size);requireBus();udp.endPacket();
        }
        // Loss in radio/network is detected from DRDY-derived sequence numbers.
    } else {
        Serial.write(wire,size); // binary stream, not a Serial Plotter CSV
    }
    requireBus();lastGoodMs=millis();
}

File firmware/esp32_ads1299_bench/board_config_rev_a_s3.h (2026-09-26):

#pragma once
// Proposed Rev A digital GPIO map only. No wiring, power or human-use approval.
#if !defined(CONFIG_IDF_TARGET_ESP32S3)
#error "EEGLAB_REV_A_S3 requires CONFIG_IDF_TARGET_ESP32S3."
#endif
constexpr int PIN_SCLK = 12;
constexpr int PIN_MISO = 13;
constexpr int PIN_MOSI = 11;
constexpr int PIN_CS = 10;
constexpr int PIN_DRDY = 4;
constexpr int PIN_RESET = 5;
constexpr int PIN_START = 6;
constexpr int PIN_PWDN = 7;
constexpr int PIN_CLKSEL = 8;
constexpr int EXPECTED_ADS_CHANNELS = 4;

#include "bench_console.h"

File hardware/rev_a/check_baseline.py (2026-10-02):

#!/usr/bin/env python3
"""Check the Rev A design contract; this is NOT a hardware/safety validation.

Python 3.10+, standard library only. Does not access hardware or the network.
"""

from __future__ import annotations

import argparse
import json
import math
import sys
from collections.abc import Callable
from decimal import Decimal, InvalidOperation
from pathlib import Path
from typing import TypedDict, cast, get_args, get_origin, get_type_hints, is_typeddict

HERE = Path(__file__).resolve().parent
SIGNALS = {
    "SCLK": (12, 40, "out"),
    "MOSI": (11, 34, "out"),
    "MISO": (13, 43, "in"),
    "CS": (10, 39, "out"),
    "DRDY": (4, 47, "in"),
    "RESET": (5, 36, "out"),
    "START": (6, 38, "out"),
    "PWDN": (7, 35, "out"),
    "CLKSEL": (8, 52, "out"),
}
# Deliberately conservative exclusions for the selected N8R8 devkit, not a
# universal description of all ESP32-S3 variants.
EXCLUDED_GPIOS = {
    0,
    3,
    19,
    20,
    26,
    27,
    28,
    29,
    30,
    31,
    32,
    33,
    34,
    35,
    36,
    37,
    38,
    43,
    44,
    45,
    46,
    48,
}
GATES = {
    "board_profile_reviewed",
    "firmware_port_validated",
    "schematic_released",
    "purchase_approved",
    "human_connection_allowed",
}


class ClockInputPull(TypedDict):
    ads_pin: int
    reference: str
    return_net: str


class AfeProfile(TypedDict):
    mpn: str
    channels: int
    sample_rate_sps: int
    gain: int
    reference: str
    reference_v: float
    clock: str
    clock_hz_nominal: int
    clk_sel_level: int
    clock_input_pull: ClockInputPull
    clock_output_enabled: bool
    daisy_chain: bool
    frame_status_bytes: int
    bytes_per_channel: int
    frame_bytes: int
    input_modes_initial: list[str]
    external_dummy_mode_enabled: bool
    lead_off_enabled: bool
    bias_drive_enabled: bool
    srb1_enabled: bool
    srb2_enabled: bool


class McuProfile(TypedDict):
    board_mpn: str
    preferred_pcb_revision: str
    module_mpn: str
    target: str
    onboard_regulator_supplies_mcu: bool
    capture_buffer_memory: str
    psram_required: bool
    wifi_enabled_initially: bool
    ble_enabled: bool


class PowerProfile(TypedDict):
    topology: str
    external_source_nominal_v: float
    external_source_tolerance_fraction: float
    external_source_capacity_a: float
    avss_v: float
    avdd_design_v: float
    avdd_operating_min_v: float
    avdd_operating_max_v: float
    analog_feed_resistance_ohm: float
    analog_branch_design_current_budget_a: float
    dvdd_v: float
    dvdd_regulator_mpn: str
    dvdd_regulator_supplies_mcu: bool
    common_ground: bool
    devkit_usb_and_5v_header_simultaneous: bool
    battery_selected: bool
    charger_fitted: bool


class InputProfile(TypedDict):
    channels: int
    topology: str
    series_resistance_each_ohm: float
    differential_capacitance_f: float
    common_mode_capacitance_fitted_f: float
    clamp_population: str
    nominal_dummy_common_mode_v: float
    bias_feedback_resistance_ohm: float
    bias_feedback_capacitance_f: float
    bias_output_series_resistance_ohm: float


class IntegrationProfile(TypedDict):
    existing_firmware_modified: bool
    existing_model_defaults_modified: bool
    preserve_simulated_channel_counts: list[int]
    requires_explicit_s3_firmware_profile: bool
    do_not_remove_existing_target_guard: bool
    this_json_is_not_loaded_by_existing_firmware: bool


class SpiSignal(TypedDict):
    signal: str
    gpio: int
    ads_pin: int
    direction_from_mcu: str


class SpiProfile(TypedDict):
    mode: int
    clock_hz: int
    pin_map_status: str
    signals: list[SpiSignal]


class PowerupControls(TypedDict):
    SCLK: int
    MOSI: int
    CS: int
    RESET: int
    START: int
    PWDN: int
    CLKSEL: int


class InterfaceHeader(TypedDict):
    mpn: str
    pin_map: dict[str, str]


class BoardProfile(TypedDict):
    schema_version: int
    profile_id: str
    revision: str
    status: str
    gates: dict[str, bool]
    afe: AfeProfile
    mcu: McuProfile
    spi: SpiProfile
    power: PowerProfile
    input_network: InputProfile
    powerup_controls: PowerupControls
    interface_headers: dict[str, InterfaceHeader]
    integration: IntegrationProfile


class PartSpec(TypedDict, total=False):
    channels: int
    module: str
    output_v: float
    rated_output_current_a: float
    supplies_mcu: bool
    resistance_ohm: float
    tolerance_fraction: float
    rated_power_w: float
    capacitance_f: float
    dielectric: str
    rated_voltage_v: float
    diodes_per_package: int


class BomItem(TypedDict):
    id: str
    mpn: str
    manufacturer: str
    description: str
    package: str
    references: list[str]
    quantity: int
    population: str
    planning_unit_usd: str
    source_ids: list[str]
    evidence: str
    spec: PartSpec


class Allowance(TypedDict):
    id: str
    description: str
    planning_usd: str


class BillOfMaterials(TypedDict):
    schema_version: int
    revision: str
    scope: str
    currency: str
    prices_are_quotes: bool
    line_items: list[BomItem]
    allowances: list[Allowance]
    budget_target_usd: str
    excluded: list[str]
    purchase_approved: bool


class RepositorySource(TypedDict):
    url: str
    live_read_succeeded: bool
    upstream_commit: str
    remote_write_succeeded: bool
    delivery: str


class SourceIdentifier(TypedDict):
    id: str


class SourceReport(SourceIdentifier, total=False):
    filename: str
    sha256: str
    authority: str


class PrimarySource(SourceIdentifier, total=False):
    title: str
    url: str
    sections: str
    verification: str


class SourcesDocument(TypedDict):
    schema_version: int
    review_date: str
    repository: RepositorySource
    reports: list[SourceReport]
    primary_sources: list[PrimarySource]
    limitations: list[str]


class CostTotals(TypedDict):
    fitted: Decimal
    dnp_options: Decimal
    allowances: Decimal
    planning_total: Decimal


def _object_items(value: object, path: str) -> dict[object, object]:
    if not isinstance(value, dict):
        raise ValueError(f"{path}: expected an object")
    return value


def _check_record_shape(value: object, schema: object, path: str) -> None:
    # is_typeddict is checked by the dispatcher before introspecting this class.
    hints: dict[str, object] = get_type_hints(cast(type, schema))
    required: frozenset[str] = getattr(schema, "__required_keys__", frozenset[str]())
    values = _object_items(value, path)
    for name in required:
        if name not in values:
            raise ValueError(f"{path}: missing {name}")
    for name, expected in hints.items():
        if name in values:
            _check_shape(values[name], expected, f"{path}.{name}")
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

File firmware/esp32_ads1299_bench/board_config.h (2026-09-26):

#pragma once
// Do not change this until HARDWARE_GUIDE.md and your actual board schematic
// have been reviewed. This acknowledges BENCH DIGITAL wiring only; it is NOT
// a human-use enable switch. All electrode leads remain disconnected.
constexpr bool BOARD_PROFILE_REVIEWED = false;

// Selection is explicit: compiling for S3 alone does not silently choose wiring.
#if defined(EEGLAB_REV_A_S3)
#include "board_config_rev_a_s3.h"
#else
#if !defined(CONFIG_IDF_TARGET_ESP32)
#error "Original ESP32 profile only. Select EEGLAB_REV_A_S3 explicitly for the proposed S3 map."
#endif
// EXAMPLE FOR ORIGINAL ESP32 / WROOM-32 ONLY. Not ESP32-C3 / S2 / S3 / C6.
// These are GPIO numbers, never physical header positions or "D" numbers.
constexpr int PIN_SCLK=18;
constexpr int PIN_MISO=19; // ADS1299 DOUT -> ESP32 input
constexpr int PIN_MOSI=23; // ESP32 output -> ADS1299 DIN
constexpr int PIN_CS=27;
constexpr int PIN_DRDY=26;
constexpr int PIN_RESET=25;
constexpr int PIN_START=32;
constexpr int PIN_PWDN=33;

#endif

// Only the internal mux paths exist in this starter. External EEG acquisition
// needs a board-specific protection, bias and reference design/review first.
constexpr bool USE_INTERNAL_TEST=true; // false = internal input-short noise test
constexpr bool USE_WIFI_UDP=false;    // false = serial console (S3 header UART), BENCH ONLY
constexpr char WIFI_SSID[]="EDIT_ME";
constexpr char WIFI_PASSWORD[]="EDIT_ME";
constexpr char UDP_HOST[]="192.168.1.2"; // replace with private-LAN computer IP
constexpr unsigned short UDP_PORT=9000;

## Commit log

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2026-09-24 fix(simulation): preserve strict types and invalidate failed study attempts
    [rev_a.py]
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2026-09-24 fix(simulation): derive completion status from immutable validated evidence
    [rev_a.py]
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2026-09-25 fix(simulation): publish and verify immutable Rev A run generations
    [rev_a.py]
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2026-09-25 fix(simulation): reconcile review regressions and verify native completion
    [rev_a_bias_overload.py]
2026-09-25 fix(simulation): verify raw completion and preserve overload event evidence
    [rev_a_bias.py, rev_a_bias_overload.py]
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2026-09-25 fix(firmware): bind target build evidence to the explicit source commit
    [test_firmware_s3.py]
2026-09-25 fix(firmware): invalidate stale build evidence before ordinary checks
    [test_firmware_s3.py]
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2026-09-25 fix(simulation): retain rejected switch completion separately from compatibility
    [rev_a_power.py]
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2026-09-25 fix(simulation): bound power inputs and preserve native probe failures
    [rev_a_power.py]
2026-09-25 fix(simulation): require raw power integration completion before comparison
    [rev_a_power.py]
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2026-09-25 fix(simulation): retain power evidence and gate completed native executions
    [rev_a_power.py]
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2026-09-26 feat(power): isolate enable and supply shutdown with shared immutable stimuli
    Six new software regressions failed against the unchanged implementation locally
    and in locked CI (500 existing tests plus 5 subtests still passed). Describe four
    fixed stimuli in the existing power module and export VIN, EN and VOUT under
    report schema 2. Preserve the exact library adapter, process boundary, tolerances,
    load/capacitor assumptions, failure retention and false validation gates.
    Adjust existing software doubles to the declared stop time and ten total probes;
    55 focused software checks now pass locally. Native and complete quality gates
    must still pass on this candidate before merging.
    [rev_a_power.py]
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2026-09-26 test(power): expose the native oracle blind spot with swapped-input injection
    [test_power_shutdown_controls.py]
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2026-09-26 feat(power): bound shared-source analog-feed startup and burst response
    Implement the saved test-first contract using a pure Thevenin solution and an independent two-node ngspice exporter through the existing public analog runner. Five fixed hypotheses retain execution/comparison/margin outcomes separately. Native diagnostics run before native pytest. No regulator model adoption, dependency, hardware, firmware or safety-gate change.
    Local candidate tree76482364 matches this published tree exactly. Pre-review full locked native gate passed609software+5subtests,53native,704/870actual branches with unchanged71%floor.63software tests failed on the final test-only tree before implementation. Nin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
    [rev_a_supply.py]
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2026-09-26 test(firmware): specify controlled Rev A startup and blocked prefixes
    Observed against 7d61786: 10 intended failures in locked local pytest (missing sequencing call/header). Existing full tools.check also reproduces the missing CLKSEL pin-map failure. These are red tests, not target or physical evidence.
    [test_firmware_startup.py]
2026-09-26 fix(firmware): execute controlled S3 clock and reset startup
    Keep the false review gate and legacy ESP32 path. Add GPIO8 CLKSEL, low latch preparation, separate operator rail/fixture and VCAP1 confirmations, and post-wake tPOR/reset ordering. These are not voltage sensing or physical approval.
    The locally tested tree is byte-identical (0aa2b3b188b97612b25886c0f6f85a123dd23528). Locked ordinary gate: 614 passed, 66 deselected, 7 subtests; branch coverage 704/870. Focused native/profile tests: 28 passed. Eleven deliberately broken sequences rejected; a benign pre-wake delay passes. Actual target/native CI remains separate.
    [board_config_rev_a_s3.h, esp32_ads1299_bench.ino, test_firmware_s3.py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]
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2026-09-26 fix(hardware): terminate the external clock during controlled startup
    Follow up exact-head Codex finding with a datasheet-verified correction: CLK is pin 37, not pin 51. Declare a fitted R_CLK_DN to DGND, adding one instance of the existing 10 kohm resistor MPN ($0.06 planning allowance). Keep clock output and all review/purchase/body gates disabled.
    Test-only parent retains six intended failures. Focused contract checks: 31 passed and 7 subtests. Ordinary stages of tools.check: 620 passed, 80.92% branch coverage. Local native export was incomplete (missing spinit/code models), so its rejection is installation evidence, NOT an ngspice compatibility result. Local staged tree exactly matches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
    [check_baseline.py]
2026-09-26 test(firmware): exercise actual sketch startup and adapter mutations
    Test-only stacked slice after the controlled startup fix. Compile the real .ino with bounded host I/O doubles, stopping at first SPI.begin. Seven scenarios and five compiling behavioral mutants cover the default review guard, stale serial acknowledgments, integration ordering and GPIO failure. Only temporary header copies enable reviewed-path scenarios; no production escape hatch or dependency is added.
    Focused firmware suites: 40 passed. Local staged tree is byte-identical to bc636e0c2a5bed619d7851069ee3bd30181d16f7. These are host call-order tests, not MCU emulation, target compilation or physical validation.
    [Arduino.h, native_sketch_startup_test.cpp, test_firmware_sketch_startup.py]
2026-09-26 test(firmware): expose discarded SPI initialization arguments
    Exact-head Codex review found the actual-sketch double discarded the SPI pin tuple. Three new compiling mutants all survive the old oracle, producing three intended red failures locally (swapped MISO/MOSI, wrong SCLK, wrong CS). No production changes.
    [test_firmware_sketch_startup.py]
2026-09-26 test(firmware): enforce actual SPI pin tuple at the startup boundary
    Record SCLK/MISO/MOSI/CS arguments before the stub stops and check the independent expected tuple (12,13,11,10). Three previously surviving mutants now fail behavioral assertions after successful compilation. Focused firmware suites: 43 passed. Local tree matches a835dca2366c7eff3209fae9a5e910ea01f88498. No production changes or gate bypass.
    [native_sketch_startup_test.cpp]
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2026-09-26 feat(hardware): add native Rev A schematic and connectivity checks
    Recover after failed sessions with three editable native KiCad sheets, exact BOM/terminal connectivity, and a bounded stdlib parser/source-closure checker. Retire only redundant R_DAISY_DN: unused DAISY_IN is directly grounded per TI. Preserve component families, firmware, lockfile and all false approval gates.
    Test-first parents retain missing CAD/DAISY and missing checker API failures. Local retained red probes also exposed malformed-XML diagnostics, swapped footprint-library URI pairing, and missing polarized-capacitor symbol checks before correction.
    Exact published tree c36f21d04aa9130436a5ff44f3b06630f8927aec matches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
    [digital.kicad_sch, power.kicad_sch, rev_a.kicad_sch]
2026-09-26 test(hardware): expose exported BOM and symbol-cache integrity gaps
    Seven intended failures observed against 970ccbd before implementation: five local-library changes hidden by embedded caches, one partial nonempty BOM CSV and one missing native DNP flag. Preserve the original KiCad-generated CSV as an independent fixture. Local test-only tree cd7204791dd635bcb153384750b3c6aa1ca0bc79 matches this tree exactly. Software process doubles are not native execution; a separate real KiCad probe also confirmed zero ERC violations for the library-only ADC pin change.
    [rev_a_bom.csv]
2026-09-26 fix(hardware): verify native BOM and embedded symbol integrity
    Address both exact-head Codex findings from 970ccbd. Validate every native CSV row and field against the already-validated XML inventory, including DNP/off-board parts. Check full project-local symbol bodies against each used embedded definition with bounded read-only structure; no CAD rewriting or external framework. Pin export locale and include both internal validators in the closed input snapshot.
    Test-only parent preserves seven observed failures. Focused software/native checks: 197 passed (187 software and ten actual KiCad cases). Both new real source faults are ERC-clean and graph-valid, then rejected by the new checks. O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
    [schematic_bom.py, schematic_sources.py, schematic_symbols.py]
2026-09-26 test(hardware): expose missing physical harness and bench console route
    Observed nine initial failures against main before implementation: missing harness API, accepted S3 USB-CDC configuration, and seven actual-sketch cases lacking explicit console pins. The implementation will refine the guard case to retain the original onboard diagnostic console until BOARD_PROFILE_REVIEWED is true; that initial overbroad guard expectation is preserved here rather than hidden. All other evidence remains software-only or native-host call-order, not physical qualification. Test-only tree f9fac40e80ce64cd50235e3fb853c575ab9e46f7 matches the local executed red tree.
    [Arduino.h, native_sketch_startup_test.cpp]
2026-09-26 test(firmware): keep external console behind the existing review gate
    Refine the initial overbroad console expectation: unreviewed S3 and legacy ESP32 retain their original default console; only reviewed S3 uses explicit header pins. Add four compiling mutations for swapped/default/baud/early-enable mistakes. Replayed these test files against unchanged main in a fresh locked worktree: eight intended failures and three passing controls (S3 guard, legacy guard, CDC-off header). No production code is included. Tree 95641fdab3b91c4c3882346d5adf41ddf3e3669c matches the replay input.
    [native_sketch_startup_test.cpp, test_firmware_sketch_startup.py]
2026-09-26 feat(hardware): derive physical harness and isolate reviewed application console
    Derive 13 board-qualified terminal groups (38 endpoints, all 20 J_DIG contacts) from the checked native schematic, existing board/BOM and manufacturer DevKit V1.1 header evidence. S3 UART0 uses explicit RX17/TX18 at 460800 8N1 only after BOARD_PROFILE_REVIEWED; the false-gate and legacy paths retain their original console. Pin CDC off, reject incompatible CDC compilation, and retain harness.json with source/artifact hashes through the existing schematic gate.
    No CAD, ADS GPIO, component family, power topology, dependency or approval gate changes. External console interface remains unselected and unqualified; VC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
    [board_config.h, board_config_rev_a_s3.h, esp32_ads1299_bench.ino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]
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2026-09-27 test(hardware): expose same-name footprint pad geometry drift
    Nine intended failures observed before implementation against merged source tree ada6c096: renamed ADS/LDO/diode pads, mirrored reference pad, collapsed VCAP land, undersized header drill, small 0603 land, wrong 0805 copper side and shifted resistor pad all passed the old hash-only snapshot. Canonical control passes. The final compressed native-fixture form was replayed on unchanged273: nine failures and one pass. Fixtures retain unmodified KiCad9.0.2-1 sources and library license; compression is not native execution evidence.
    Tree d19f5c2c73c151eb36911c37f13701b937caf045 matches the replay input. Parent273 is the reviewed source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
    [footprint_fixtures.py]
2026-09-27 feat(hardware): publish recovered footprint geometry review
    Recover the complete local candidate c458dd4449632f0f977d30ef2d01b9aa557c1ca7 after the prior publication blocker. The uploaded tree 4bd0592b0757549bbc65809ea817a4b960341f60 is byte-identical; the remote test-only parent c72cb83 preserves the original nine failing probes. No reconstructed circuit or new component/firmware/rail/dependency change.
    The restored locked environment reran the clean candidate: 937 ordinary tests plus 7 subtests, 88 native/integration, 21 actual KiCad cases, 1045/1226 branches; zero canonical ERC violations. Its 22 repeated console cases are a subset of 88. Footprint checks freeze inspected geometry, not m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
    [footprint_geometry.py, schematic_sources.py]
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2026-09-27 fix(hardware): require distinct pad matches and preserve native equivalence
    Address both independently reproduced exact385 Codex findings. Consume each expected land exactly once instead of allowing two near-coincident nonpolar pads to reuse one partner. Keep the existing numeric tolerance and legitimate nonpolar reversals. The native loader now applies that same acceptance contract rather than an extra literal fixture-equality rule; three benign copied-library swaps reach KiCad export, and a loadable near-duplicate is rejected.
    Test-only parent56dff preserves eight observed failures with three passing tolerance controls. Focused footprint suites:86passed. Full locked local gate on exacttre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
    [footprint_geometry.py]
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2026-09-27 feat(power): invert the existing rail window for bulk qualification
    Reuse the piecewise RC response at unit source voltage to return the required minimum and allowed maximum source amplitude over the existing4..20ms interval. A reversed interval explicitly means no solution. Share extrema with forward metrics and retain the new fields through the existing five-case study; no new solver/runner/model parameters.
    Also retain the manufacturer-authored2023 mirrored sheet establishing L/K packaging and e/g terminal geometry for the preferred bulk core. ExactL is a qualification target, not an approved BOM replacement. Old reference URL404/mirror failure and incomplete assembly evidence remain exp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
    [rev_a_supply.py]
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2026-09-27 feat(power): make supply timing and source-band coverage explicit
    Add immutable SupplyTiming to the existing supply hypothesis and propagate it through analytical state, native PWL sources, integration checks, inverse extrema, CLI and retained reports. Only events within the observation interval constrain extrema; all earlier capacitor history remains. Changing observation alone never changes the physical trajectory. Default traces, netlists and inverse outputs match retained pre-edit controls exactly.
    Distinguish a feasible mathematical source from coverage of the entire configured source tolerance band. The original five cases and model parameters remain unchanged; this is no device start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
    [rev_a_supply.py]
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2026-09-27 fix(power): observe custom source transitions before claiming completeness
    Address the independently reproduced Codex finding from05f48d8. Preserve the historical10ns near-zero allowance but also require the first observation no later than the requested source-on. Source-on zero requires an actual zero-time sample. Default waveforms, experimental parameters and all hardware gates remain unchanged.
    Test-only parent22d5c81 preserves two observed false-acceptance failures with five controls. Two actual early/zero-source native studies retain initial samples and pass. All146 focused supply tests now pass; strict typing and real commit hooks pass. Published tree e9edc3ee919ea65234aae3574dea2340e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
    [rev_a_supply.py]
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2026-09-27 fix(power): emit a unique zero-time source vertex
    Actual ngspice42 CI failed initial operating-point solution with NaNs for the zero-source-on test; diagnostic commit030ec87 retains the reports and bounded simulator-log tails. The generated PWL contained duplicate t=0 vertices. Native44.2 had completed with a warning, not established portable input validity.
    Test-only3415f58 preserves one observed monotonic-PWL failure and two controls. Omit only the redundant origin when source-on is zero, preserving positive-source netlists byte-for-byte, source amplitude,1ns edge, ideal response and strict first-sample rule. No fabricated initial sample, skip or relaxed tolerance. All12 initial-observati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
    [rev_a_supply.py]
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2026-09-27 feat(hardware): publish T491 nominal lands with one fixture pending
    The editable local footprints, source/library closure, geometry and courtyard checks, CAD assignments, CSV and tests are published. Remote tree8aa713cd369f7514c97ca628035464c9259c4497 differs from the fully tested local tree4fc3a080680de93b56419376709d76b4b957a0b7 only at tests/fixtures/rev_a_netlist.xml.gz, whose old bytes remain pending transport. Do NOT treat this commit as the full green candidate or merge it.
    The clean local2a8c662 candidate passed1051 ordinary+7subtests,98 native/integration,25 actualKiCad cases,1098/1278branches and0ERC findings. Actual native export comparison permits exactly the C_REF/C_VCAP1 footp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
    [power.kicad_sch, rev_a_bom.csv]
2026-09-27 fix(hardware): validate the complete local courtyard stroke
    Address Codex courtyard finding after twelve observed failing stroke faults and two passing equivalent controls. Require one 0.05 mm continuous default stroke with one width/type pair. Actual local footprint files and component choices are unchanged.
    This published tree 885d222eb3fc59449865ef2d4c984f987a805668 was independently reproduced in an isolated local Git index: it differs from the fully tested local tree 8e1f0679c9cf1306ce9f40ebb72dcaceaace73e6 ONLY at the still-stale tests/fixtures/rev_a_netlist.xml.gz. The complete fixture and verified one-file patch are retained in the delivery. Do not call this partial remote head gree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
    [footprint_geometry.py]
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2026-09-28 feat(hardware): import the checked schematic into an editable native PCB
    Add a one-shot pure importer using the existing graph, footprint and bounded syntax checks. Preserve all 68 on-board instances, 245 physical pads, native paths, values/MPNs and eight DNP flags; exclude the logical off-board module. The output is an explicitly unrouted parking grid, not placement, an outline, a chosen stackup or fabrication approval.
    Actual native tests export fresh schematic XML, read installed/local footprints, load the resulting board and run KiCad schematic parity. Canonical has zero parity issues; wrong reference, missing component and wrong net copies are detected. Unconnected routes, missing outl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
    [pcb_seed.py]
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2026-09-28 feat(hardware): route local reference and VCAP capacitor networks
    Complete the five sensitive positive nets on front copper and add explicit local capacitor return traces. Preserve existing ADC-side routing, schematic, BOM and all approval flags. Two previously unrouted capacitors move for locality/clearance. Native cut-trace and cut-return controls pass; the full local gate remains to be executed on this commit. This is reconstructed local history, not a published GitHub head.
    [rev_a.kicad_pcb]
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2026-09-28 feat(hardware): connect native ground plane and supply routes
    Rebuild only the missing post-reference routing: one actual KiCad-filled In1 ground region and distinct VIN, AVDD and DVDD routes. Preserve all component data and existing copper. Canonical native DRC has zero parity/other findings and 35 deliberately unfinished connections. Require actual refill before testing each mutated board, reject missing/clipped planes and cut supply traces, and bind the new test source in the existing snapshot. No physical, purchasing, BOM, circuit, firmware, model or dependency change; full final local gate follows on this commit.
    [rev_a.kicad_pcb]
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2026-09-29 fix(pcb): provide direct local AVDD1 bypass and return paths
    Move five existing capacitors, preserving their electrical identities and the other 63 footprint forms. Four AVDD1 front paths now pass the preceding native failures. Fresh all-severity parity/DRC is 0/0/0. Two reconnection controls preserve general DRC/connectivity but fail the direct local paths; benign track subdivision remains accepted. VCAP3 paths stay front-only, with the longer HF path and AVDD56 tradeoff to be documented explicitly; no performance or approval claim.
    [rev_a.kicad_pcb]
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2026-09-29 fix(hardware): reroute digital outputs over In1 with bounded local escapes
    Preserve every footprint and all non-output copper. Move MISO and DRDY long spans from B to F, with short In2 escapes beside the ADC. Two original native red cases precede this repair. Connected wrong-layer and reference-window mutations are rejected; track reversal/subdivision are accepted. Existing output-cut locations now select new trunk segments. Four output-via fill openings are distinct after native refill. This is geometric layout verification, not measured noise or body-use qualification.
    [rev_a.kicad_pcb]
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2026-09-30 fix(hardware): move CH1N outside the filtered input branch corridor
    Preserve the failure-first native policy commit. Change only CH1N copper and fresh native-filled ground; retain all footprints, main filter paths and other nets. Add three harmful DRC-clean controls and three scoped benign controls. The route grows to 33.884 mm; this is not a noise or length-matching guarantee.
    [rev_a.kicad_pcb]
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2026-09-30 fix(hardware): migrate both bench headers to the high-temperature HTSW selection
    [digital.kicad_sch, rev_a.kicad_pcb, rev_a.kicad_sch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]
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2026-09-30 fix(mechanical): clear cable envelope and require native CAD execution
    [carrier_k2.scad]
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2026-09-30 fix(mechanical): make raised guides removable for populated-board installation
    [carrier_k2.scad, view_k2.scad]
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2026-09-30 fix(mechanical): clear both cable exits across the complete carrier assembly
    [carrier_k2.scad]
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2026-10-01 fix(mechanical): construct guide bridges in one datum for valid STL facets
    [carrier_k2.scad]
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2026-10-01 test(hardware): expose C3 missing schematic and incompatible bus pull loading
    [test_auxiliary_contract.py]
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2026-10-01 fix(hardware): close auxiliary ERC inputs and correct ISO channel labels
    [auxiliary.kicad_sch]
2026-10-01 fix(hardware): validate complete C3 manifest and native sheet assignment
    [auxiliary.py, test_auxiliary_contract.py]
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2026-10-01 fix(hardware): update native service note and document exact JST contact suffix
    [auxiliary.kicad_sch]
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2026-10-02 test(hardware): bind auxiliary placement and clearance policy into source receipts
    [test_auxiliary_contract.py]
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2026-10-02 fix(hardware): move H4 clear of the unchanged MCU termination allocation
    [auxiliary.kicad_pcb]
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2026-10-02 fix(hardware): guard local ground continuity and bind routing evidence
    [test_auxiliary_ground.py]
2026-10-02 fix(hardware): move logic return via clear of same-net resistor pad
    [auxiliary.kicad_pcb]
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2026-10-03 test(hardware): expose ground void beneath bent bypass copper
    [test_auxiliary_ground.py]
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2026-10-10 fix(hardware): declare SPI nets before pads and import native exports
    Actual KiCad9.0.2 diagnosed five driver pads loading as no-net because
    their declarations appeared after footprints. Move only declarations;
    retain numeric nets, pad fields and planar routes. Remove exactly two
    native-DRC single-layer via stubs and extend only the explicit L5 delta.
    Use genuine native XML/CSV from immutable source27c6525d/run38074668398.
    Reconcile exact inventory increases, preserving all mutation loops.
    One AST-preserving formatter fix. Fourteen files, independently fixed
    expected treebd59a0c. No original snapshot, firmware, Q1, workflow or
    dependency/gate changes. Installed-pytest338 focused passes local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
    [auxiliary.kicad_pcb, rev_a.kicad_pcb, rev_a_bom.csv]
2026-10-10 fix(hardware): save the verified native auxiliary ground fill
    Transplant only the TARGET_GND filled_polygon from actual KiCad9.0.2
    run38075526473 on f5338e69. Zone outline/settings and every other
    authored byte are unchanged. The other seven zone forms, including
    the AFE ground fill, already match the fresh native output exactly.
    Both refilled boards had zero parity/DRC/unfinished findings; all15
    native L5 cuts/bridges passed. This is not a full gate or release.
    Remaining S2-S4 source binding and K2 review must not be waived.
    [auxiliary.kicad_pcb]
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
